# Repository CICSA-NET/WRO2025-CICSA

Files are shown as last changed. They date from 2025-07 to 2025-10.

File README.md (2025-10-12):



This is the official repository of the Team CICSA for the international final of the WRO2025 season in Panamá.

## Follow us!

| Facebook | YouTube | Instagram |
|---|---|---|
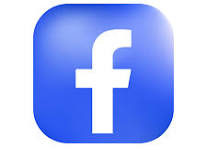
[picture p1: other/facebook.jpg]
Facebook (https://www.facebook.com/share/1A1hz6zQSn/)
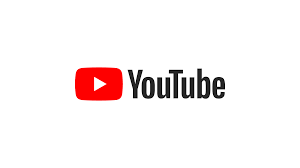
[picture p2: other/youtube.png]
YouTube (https://www.youtube.com/@CICSA_Academia)
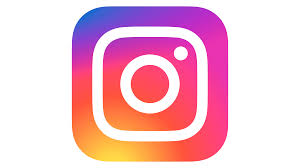
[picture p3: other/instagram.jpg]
Instagram (https://share.google/ZzGMFZOurGsjhWN2D)
|  |  |  |

## Contents.
**Folders**
- [📁 Models](./models/)
- [📁 Other](./other/)
- [📁 Schemes](./schemes/)
- [📁 Src](./src/)
- [📁 T-photos](./t-photos/)
- [📁 V-photos](./v-photos/)
- [📁 Video](./video/video.md)

**Index**

- [The team](#The-team)
- [The Challenge.](#The-Challenge)
- [Robot Overview](#Robot-Overview)
- [Robot construction guide.](#Robot-construction-guide)
- [Engineering materials](#Engineering-materials)
- [Mobility Management](#Mobility-Management)
- [Power and Sensor Management](#Power-and-Sensor-Management)
- [Obstacle management](#Obstacle-management)
- [Performance videos](#Performance-videos)
- [Digital Engineering Logbook](https://github.com/CICSA-NET/WRO2025-CICSA/blob/main/other/README.md)
- [Final Remarks and future work](#Final-remarks-and-future-work)
- [References](#References)

___
## The team.
====

CICSA WRO 2025 - Future Engineers

Coach **Sergio Iván Hernández Ruiz**

Coach Sergio Iván provides the technical guidance and leadership required to keep Team CICSA on track. With extensive experience in robotics, he helps us navigate complex challenges, refine our designs, and develop solutions that work in competitive and real-world settings.

Sergio Iván has been the director of the CICSA robotics academy since 2015 and has participated in events organized by the WRO since 2019.
***
**Members:**

**Iván Ramón Hernández Gónzalez**, at 22 years old, he studies Electronics Engineering at the Instituto Tecnológico de Nogales. He participated in the WRO regional competition in 2019, obtaining 1st place in the preparatory category in the city of Guadalajara, Jalisco, México. In 2024, he was the coach of the CICSA team that participated in the ChampionShip of Italy, with an outstanding performance. In 2025, he participated as a coach in the Robotics Championship, an event affiliated with the Baja Robotics League, in Tijuana, Baja California, México, obtaining 2nd place in the Zumo Kit educational competitions category.
***
**Sergio Amid Hernández Gónzalez**, at 19 years old, he studies Software Engineering at Kuepa University. He has participated in numerous competitions, including: the 2019 WRO Regional in Guadalajara, Jalisco, México, where he obtained 1st place. In 2024, in the city of Mexicali, Baja California, México, they obtained 1st place in the preparatory category. He was part of the Mexican robotics team that represented Mexico at the ChampionShip in Italy in 2024.
***
**Xiara Gabriela Alcantar Dorame**, she is 20 years old, studies Mechatronics Engineering at the Universidad Tecnológica de Nogales, in 2020 she was part of the CICSA team that would represent CICSA in the regional competition, but the pandemic prevented the event from taking place, for 2025 she will be part of the CICSA representative in the National competition in Rosarito, Baja California, México.

___



[📁 T-photos](./t-photos/)

[Menu](#Contents)

___

## The Challenge.
====

The WRO Future Engineers challenge pushes students to create fully autonomous self driving vehicles. Each robot must:

- Navigate a dynamically randomized track.
- Detect and avoid colored obstacles (green/red blocks).
- Execute a parallel parking maneuver.

Scoring is based on:
- Performance on track.
- Obstacle handling.
- Documentation quality.
- Innovation and engineering rigor.

Objective:
Design and build a mobile robot capable of autonomous navigation using: 
* Image recognition for object detection.
* PID control to maintain a safe distance from obstacles using ultrasonic sensors.
* Communication between Raspberry Pi 5 and ESP32 to divide tasks between heavy processing (vision) and real-time control (motors and sensors).

**Open challenge.**



**Obstacle challenge.**



For more indo visit: [WRO Official Site](https://wro-association.org/)

[Menu](#Contents)
___

## Robot Overview.
====

| Front | Back | Top |
|---|---|---|
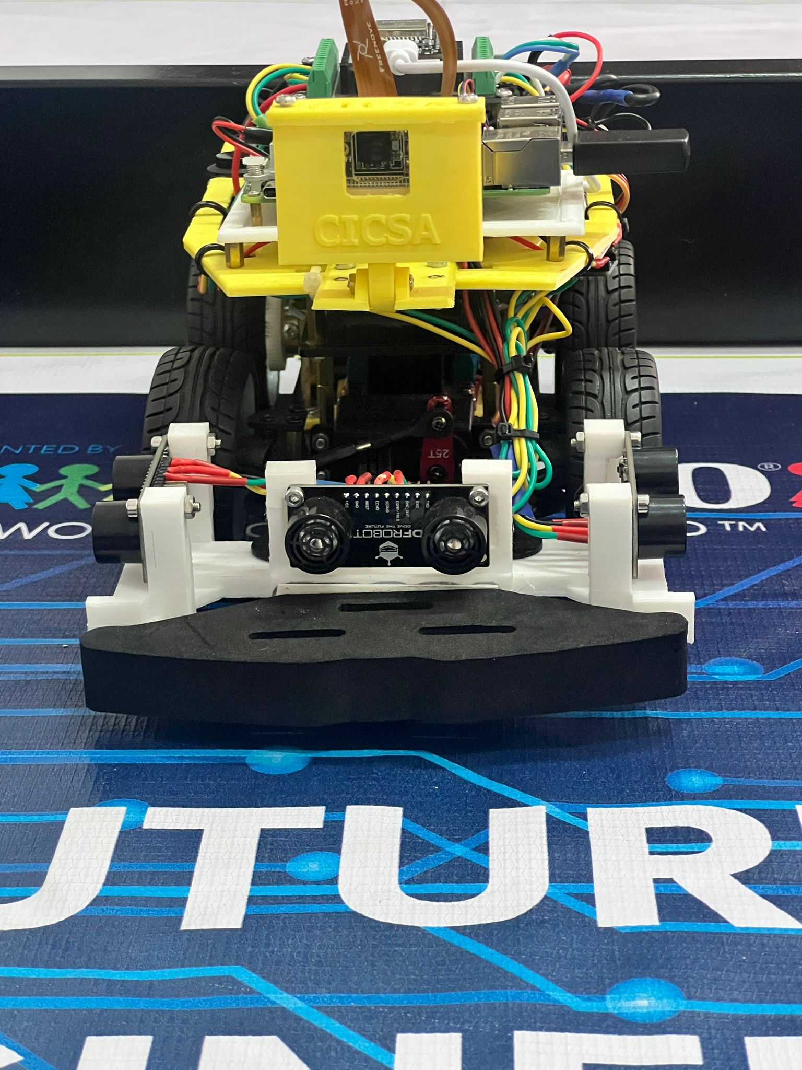
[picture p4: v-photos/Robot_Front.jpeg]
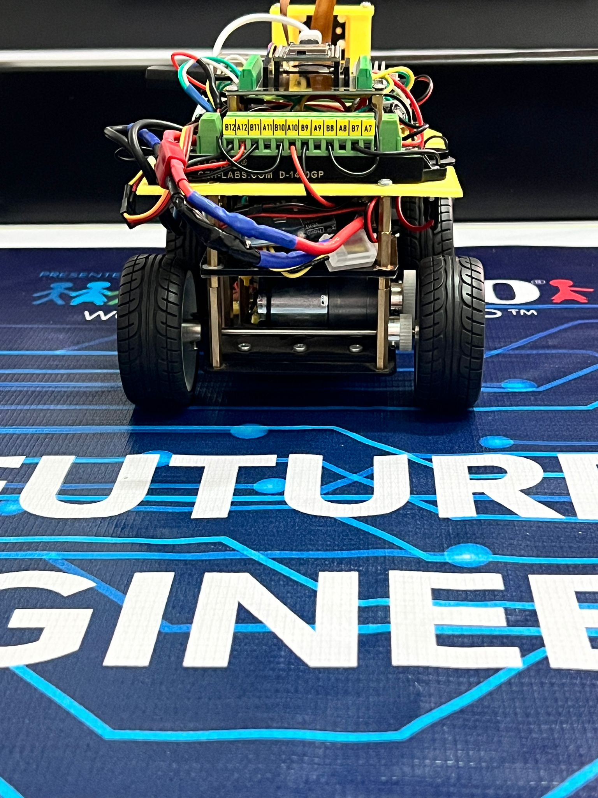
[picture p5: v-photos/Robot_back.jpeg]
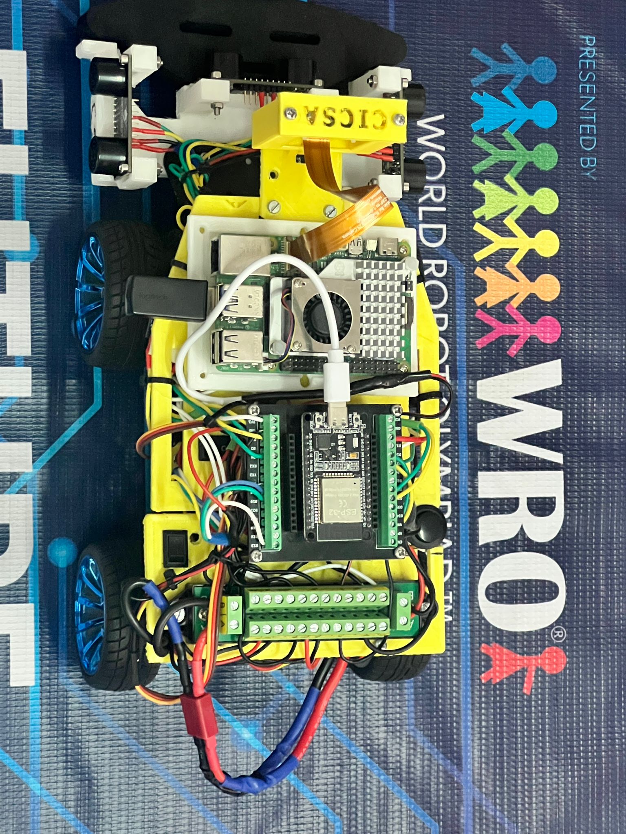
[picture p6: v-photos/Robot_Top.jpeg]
|  |  |  |

| Bottom | Left | Right |
|---|---|---|
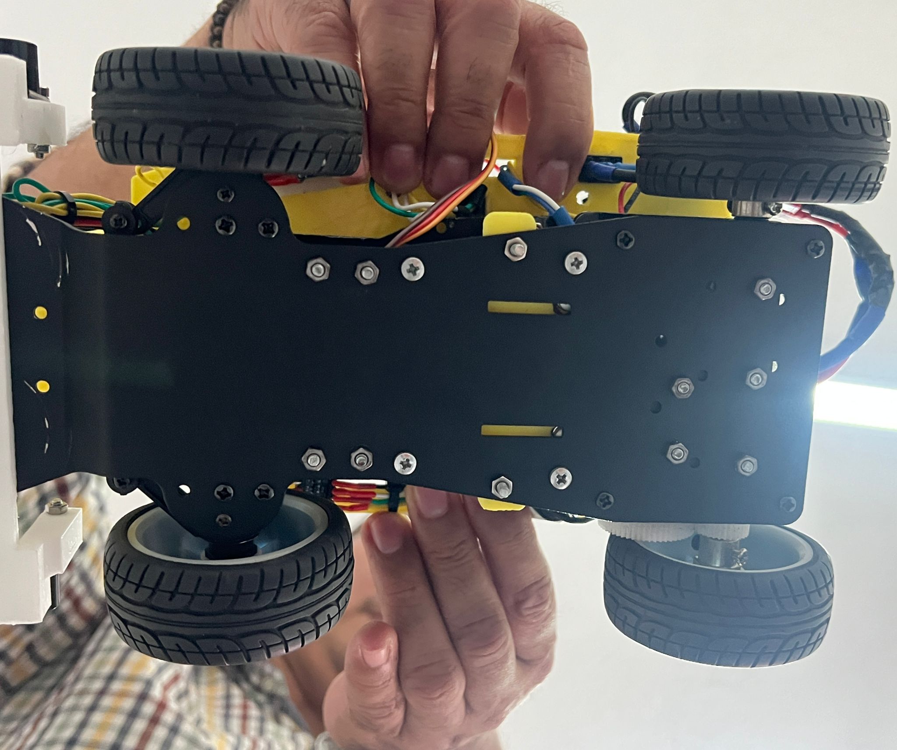
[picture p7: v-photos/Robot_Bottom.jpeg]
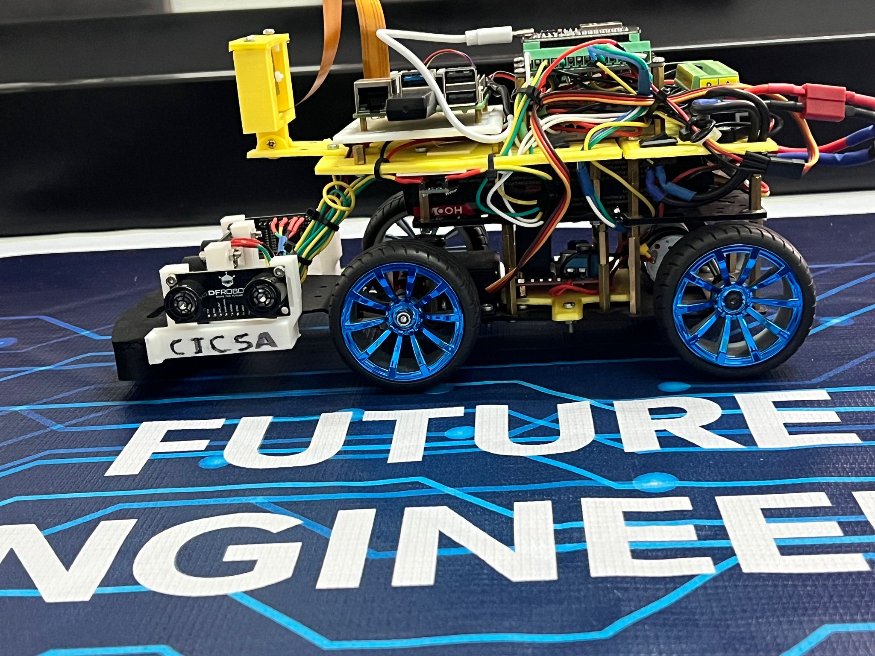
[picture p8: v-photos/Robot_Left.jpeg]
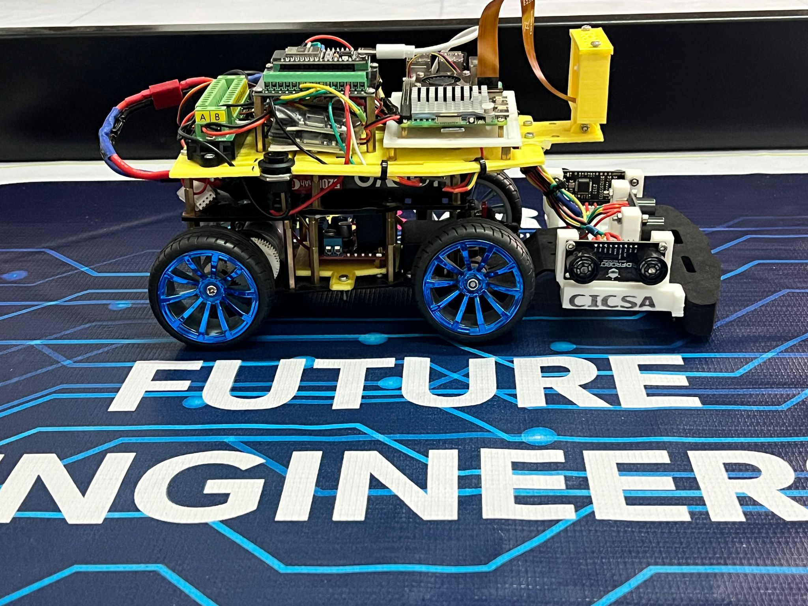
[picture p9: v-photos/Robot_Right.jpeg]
|  |  |  |

| Side Dimensions | Front Dimensions | Robot Weight| 
|---|---|---|
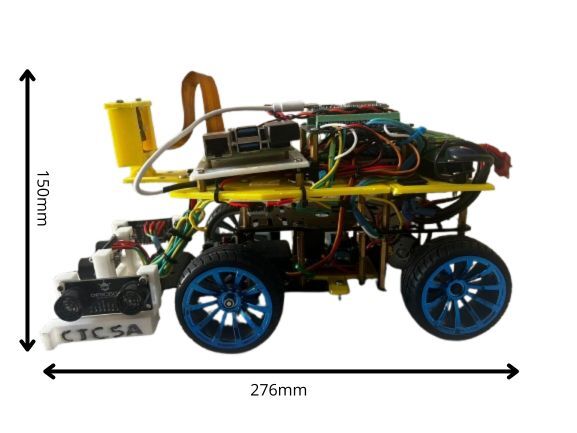
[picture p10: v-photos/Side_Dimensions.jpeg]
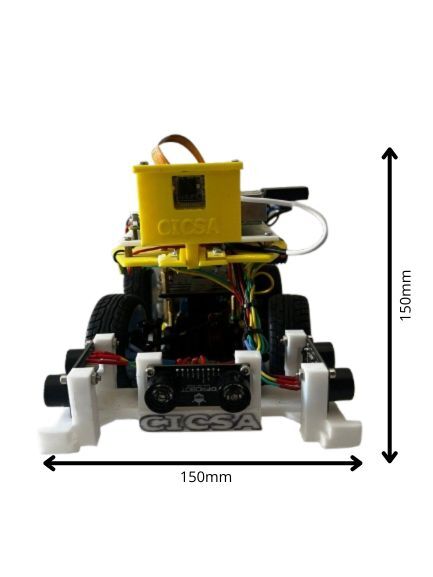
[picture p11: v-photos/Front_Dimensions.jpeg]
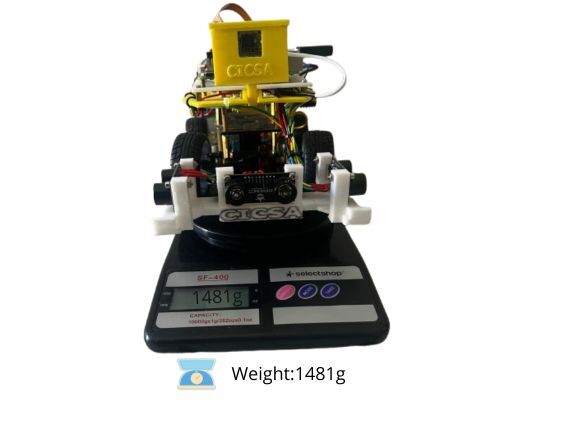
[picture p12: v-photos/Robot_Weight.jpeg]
|  |  |  |

| Evolution of the robot |
|---------------|
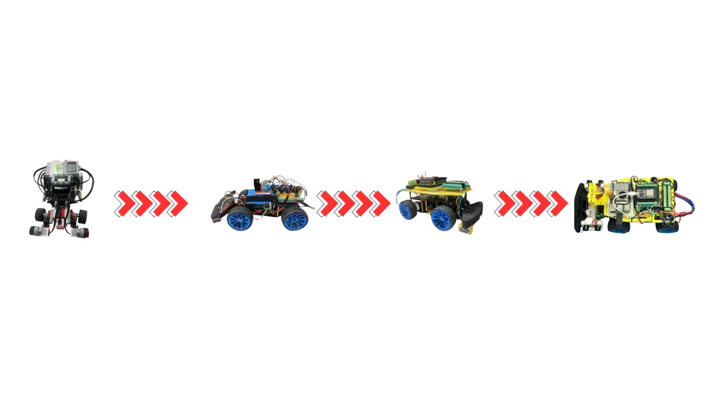
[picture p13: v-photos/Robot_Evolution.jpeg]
|  |

[Menu](#Contents)
___

## Robot construction guide.
====

**Assembly Guide.**

This guide provides step-by-step instructions for assembling the robot chassis. It includes mechanical installation, electrical wiring, and safety notes for robotics projects using ESP-32, Raspberry Pi 5, camera and sensors.

---

**Component List.**

| Component | Quantity | Description |
|---|---|---|
| JGA25-370 DC Motor | 1 | Gear motor for drive system |
| Servo Motor | 1 | For front steering mechanism |
| Wheels | 4 | Includes M4 nuts |
| Bearings (large/small) | 8 | 2 per wheel |
| Steering Cup | 2 | For front wheels |
| Short Ball Head | 1 | Connects servo to steering cup |
| Steering Rod | 2 | Length: 65 mm |
| M3×5mm Screws | 4 | Servo mounting |
| M3×8mm Screws | 4 | Pillar mounting |
| M2.5×10mm Screws | 2 | Steering rod mounting |
| M3×22mm Copper Pillars | 4 | Standard chassis height |
| M3×16mm Copper Pillars | 4 | Extended front option |
| Rocker Switch | 1 | Power control |

---

**Pre-Installation Checks.**

**Servo Motor.**
- Connect and calibrate to **90°** before installation.
- Use test code or compatible software.

**DC Motor.**
- Power directly to verify rotation.
- **Red dot** indicates positive terminal.

---

**Wheel Assembly Steps.**

1. Insert rotating shaft.
2. Add large bearing.
3. Install steering cup.
4. Add small bearing.
5. Insert pin.
6. Attach hex coupler.
7. Mount wheel.
8. Secure with M4 nut.

>  Ensure bearings are parallel and wheel rotates freely.

---

**Servo & Steering Assembly.**

- Mount servo to L-bracket using M3×5mm screws.
- Connect short ball head between servo and steering cup.
- Attach steering rods using M2.5×10mm screws.

---

**Chassis Mounting.**

- Use M3×22mm pillars and M3×8mm screws for standard setup.
- For extended front space (e.g. larger battery), use M3×16mm pillars.
- [Place the base to hold the connector](models/base_conector_v3.STL)
- [Place the base to hold the L298N](models/base_l298n.stl)
- [Place the main base](models/base_principal_V6.STL)
- [Place the base to hold the support of the camera](models/base_camera_v2.STL)
- [Place the base to hold the camera](models/base_camera2_V2.STL)
- [Place the camera base cover](models/tapa_camera.STL)
- [Place the base to hold the sensors UM](models/base_urm37_v7.STL)
- [Place the base to hold the Rasoberry Pi 5](models/Base_Pi_5_v5.STL)
- [Place the shield that contains the esp32](https://www.mercadolibre.com.mx/screw-shield-adaptador-de-terminales-esp32-30-pines/p/MLM2038781113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)

For more information regarding 3D printed parts: [📁 Models](./models/)

---

**Electrical Wiring.**

**Servo Motor.**

| Wire Color | Function |
|---|---|
| Brown | GND |
| Red | VCC |
| Yellow | Signal |

**Power Switch.**

- Connect **in series** with the positive (red) wire.
- Enables safe power control.

---

**Safety Notes.**

- Do not operate in humid environments.
- Avoid reverse polarity.
- Prevent short circuits.
- Double-check connections before powering on.

---

**Board Compatibility.**

Mounting holes support:

- ESP-32 base
- Camera base
- Raspberry Pi 5 base

---

Original PDF: [Elecrow 4WD Car Installation Instructions](https://www.elecrow.com/download/4wd_CAR_Install_instructions.pdf)

---

[Menu](#Contents)
___

## Engineering materials.
====

This repository contains engineering materials of a self-driven vehicle's model participating in the WRO Future Engineers competition in the season 2025.

| Quantity | Component |Link |
|---|---|---|
| 1 | Raspberry Pi 5 (16GB) |[Amazon](https://www.amazon.com/gp/product/B0DSPYPKRG/ref=ox_sc_act_title_6?smid=A02211013Q5HP3OMSZC7W&psc=1) |
| 1 | ESP-WROOM-32 |[Amazon](https://www.amazon.com/ESP-WROOM-32-Development-Microcontroller-Integrated-Compatible/dp/B08D5ZD528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) |
| 1 | Camara Freenove 8MP |[Amazon](https://www.amazon.com/Freenove-8MP-Raspberry-Adjustable-Viewing/dp/B0BZYPBS17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) |
| 1 | Driver de motor L298N |[Amazon](https://www.amazon.com/JTAREA-Stepper-Driver-H-Bridge-Mega2560/dp/B0D2RJV2VX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) |
| 1 | Terminal Block OONO D-1410GP |[Amazon](https://www.amazon.com/Position-Terminal-Distribution-OONO-D-1410GP/dp/B0DXF1GF9Q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) |
| 2 | SoloGood 5V 5A (2s/3s/4s) |[Amazon](https://www.amazon.com/SoloGood-Module-Quadcopter-Airplane-Servo/dp/B0C3GVGYDS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) |
| 1 | External UBEC 5V BEC Multi-Purpose Step-down Power Supply Module Full Shielding Antijamming for FPV Airplane (1PC 5V 7A) |[Amazon](https://www.amazon.com/dp/B0D7MR48LB?ref=ppx_yo2ov_dt_b_fed_asin_title&th=1) |
| 1 | Battery LiPo HOOVO 11.1V 3S 5200mAh 60C |[Amazon](https://www.amazon.com/HOOVO-11-1V-5200mAh-Softcase-Helicopter/dp/B0BWJH8G35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) |
| 1 | Chasis 4WD + servo S3003 |[Elecrow](https://www.elecrow.com/4wd-smart-car-robot-chassis-for-arduino-servo-steering.html) |
| Varios | Jumper y cables |[Amazon](https://www.amazon.com/-/de/dp/B01EV70C78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)|
| 1 | Cable 24 AWG PUDKLE (157ft) |[Amazon](https://www.amazon.com/dp/B0DK57KRCT?ref=ppx_yo2ov_dt_b_fed_asin_title&th=1) |
| 2 | Logic Level Converter Bi-Directional Shifter Module 3.3V to 5V |[Amazon](https://www.amazon.com/dp/B07CXMDJC2?ref=ppx_yo2ov_dt_b_fed_asin_title) |
| 1 | Screw shield adaptador ESP-32 |[Mercado Libre](https://articulo.mercadolibre.com.mx/MLM-2162499429-screw-shield-adaptador-de-terminales-esp32-30-pines-_JM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) |
| 1 | 6pcs DIN Rail Terminal Blocks |[Amazon](https://www.amazon.com/dp/B0BQ6GWW3T?ref=ppx_yo2ov_dt_b_fed_asin_title&th=1) 
| 3 | Ultrasonic sensors URM37V5.0 |[DigiKey](https://www.digikey.com/en/products/detail/dfrobot/SEN0001/6588449) |
| 1 | USB to TTL Converter |[Amazon](https://www.amazon.com/DSD-TECH-SH-U09C5-Converter-Support/dp/B07WX2DSVB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) |

Estimated total cost ==> **$ 327.00 US dollars**.

| Component | Function / Description |
|---|---|
| Raspberry Pi 5 | Image processing and navigation logic |
| ESP32 | Real-time servo control with PID algorithms and read sensors |
| Camera | Captures images for computer vision |
| ARM37V5 (x3) | Distance measurement for obstacle avoidance |
| L298N Motor Driver | Controls DC motors |
| DC Motor | Robot movement |
| Lipo Battery | Portable power source |
| Voltage Regulator | Stabilizes voltage for sensitive components |
| UART Communication | Link between Raspberry Pi and ESP32 |
| 2WD / 4WD Chassis | Physical structure of the robot |
| Servo motor | Controls steering direction | 

Software & Libraries Overview
| Platform | Language / Frameworks | Key Functions / Roles |
|---|---|---|
| Raspberry Pi 5 | Python 3 | Main control logic, image processing |
| | OpenCV | Computer vision (line following, object tracking)|
| | pyserial | UART communication with ESP32 |
| | numpy, imutils | Math operations, image transformations |
| ESP32 | MicroPython | Lightweight firmware for real-time control |
| | machine, time, ustruct | Sensor reading, PWM generation, UART handling |
| | PID function | Servo control |

Workflow Table
| Module | Function / Task |
|---|---|
| Raspberry Pi 5 | Captures image via camera |
| | Processes image using OpenCV (color) |
| | Determines direction. |
| | Sends commands to ESP32 via UART |
| ESP32 | Receives commands from Raspberry Pi |
| | Reads ultrasonic sensor data |
| | Applies PID control to maintain safe distance |
| | Controls motors and servo using PWM |

[Menu](#Contents)
___

## Mobility Management.
====

**Design Objectives**

The mobility system was designed to meet the following goals:

- **Precision**: Achieve controlled movement and accurate steering.
- **Stability**: Maintain balance and traction across varied surfaces.
- **Mechanical Efficiency**: Use gear ratios to optimize torque and speed.
- **Adaptability**: Respond effectively to terrain changes and obstacles.

**Gear Transmission**: Power is delivered from the motors to the wheels through a custom gear system. Gear ratios were selected to enhance torque for low-speed control and obstacle negotiation.

Mobility is a key factor in robotic performance, especially in competitive environments where precision, stability, and adaptability are essential. This document outlines the mechanical and software strategies used to manage the robot's mobility, featuring a gear-based transmission system and directional control via a servomotor.





The gear transmission is a mechanical system that allows for the modification of angular velocity and torque between two connected shafts. This is achieved by coupling two gears: a driving gear (coupled to the motor) and a driven gear (coupled to the load or wheel).

Based on the previous terms, we use them in the robot as follows:

1. For the free challenge, it is required that the robot has more speed than torque, which is why the driven gear has 54 teeth in relation to the driving gear of 32. If we apply the principle of conservation of mechanical power,
  
   where:  RT =   driven gear teeth / driving gear teeth = 54 / 32 = **1.68**

2. For the obstacle challenge, it is required that the robot moves slowly and with more torque, resulting in the driven gear for this particular challenge having 32 teeth and the driving gear having 54, so that by applying the principle of conservation of power, a decrease in speed is obtained, but torque increases in the following proportion:

   where:  RT =   driven gear teeth / driving gear teeth = 32 / 54 = **0.59**

The motor is controlled using the pulse width modulation technique. Pulse Width Modulation (PWM) is a widely used technique for controlling the speed of DC motors by adjusting the effective voltage applied to the motor terminals. Instead of varying the actual supply voltage, PWM rapidly switches the motor’s power on and off at a fixed frequency, modulating the duration of the “on” time within each cycle—this is known as the duty cycle. The motor’s speed is directly influenced by the duty cycle of the PWM signal. A higher duty cycle means the motor receives power for a greater portion of each cycle, resulting in a higher average voltage and increased rotational speed. Conversely, a lower duty cycle reduces the average voltage and slows the motor down. The configuration parameters are shown below:

**These are the parameters defined for the open-category challenge:**

enable = PWM(Pin(21), freq=1000)        # Motor PWM enable

enable.duty_u16(35000)                  # Set duty cycle to ~53.4%

- Pin(21): Refers to GPIO pin 21 on the microcontroller (ESP32). This pin is physically connected to the motor driver’s (L298N) enable input, which expects a PWM signal.
- PWM(...): Initializes a PWM object on that pin.
- freq=1000: Sets the PWM frequency to 1000 Hz (1 kHz), meaning the signal completes 1000 cycles per second.
- duty_u16(...): Sets the duty cycle using a 16-bit value (range: 0 to 65535).
- 35000: Represents the “on” time of the PWM signal. The duty cycle percentage is:
  Duty Cycle(%) = (35000 / 65535) * 100                **approx 53.4\%**
- This means the signal is high (ON) for 53.4%.
- Average Voltage: The motor receives approximately 53.4% of the supply voltage. If V = 11.1 V, then:
  V = 11.1V * 0.534      **approx 6V**

Based on the measured values and the technical specifications provided by the manufacturer, the following results are obtained:

| Parameter | Measured Value | Unit |
|---|---|---|
| No-load Speed | 646 | RPM |
| No-load Current | 0.1 | A |
| Rated Torque | 0.23 | Kg-cm |
| Power | 1.5 | W |
| Load Speed | 516 | RPM |
| Load Current | 0.8 |  A |
| Stall Torque | 2 | Kg-cm |
| Stall Current | 2 | A |
| Operating Voltage | 6.0 | V |

[Reference](https://www.elecrow.com/4wd-smart-car-robot-chassis-for-arduino-servo-steering.html)

**The following parameters were defined for the obstacle challenge:**

- 26000: Represents the “on” time of the PWM signal. The duty cycle percentage is:
  Duty Cycle(%) = (26000 / 65535) * 100                **approx 39.6\%**
- This means the signal is high (ON) for 39.6%.
- Average Voltage: The motor receives approximately 39.6% of the supply voltage. If V = 11.1 V, then:
  V = 11.1V * 0.396      **approx 4.39V**

Based on the measured values and the technical specifications provided by the manufacturer, the following results are obtained:

| Parameter | Measured Value | Unit |
|---|---|---|
| No-load Speed | 472 | RPM |
| No-load Current | 0.073 | A |
| Rated Torque | 0.263 | Kg-cm |
| Power | 1.0 | W |
| Load Speed | 377 | RPM |
| Load Current | 0.58 |  A |
| Stall Torque | 2 | Kg-cm |
| Stall Current | 1.46 | A |
| Operating Voltage | 4.39 | V |

[Reference](https://www.elecrow.com/4wd-smart-car-robot-chassis-for-arduino-servo-steering.html)

**Directional Control**: A high-precision servomotor is used to steer the front axle, allowing for smooth and responsive turns. This setup mimics real-world vehicle steering and improves maneuverability in tight spaces.







The foundation of our chassis design is based on a steering configuration known as the parallel steering model, in which both front wheels turn at the same angle when steering input is applied. This approach, while mechanically straightforward, provides a reliable baseline for mobile robot steering systems—especially when simplicity, symmetry, and ease of implementation are key priorities.



In short, parallel steering was chosen because it strikes a balance between functionality and feasibility. It enables reliable performance while keeping the mechanical and computational demands accessible—perfect for STEM education, prototyping, and early-stage competition builds.

The selection was based mainly on the following reasons:

1. Mechanical Simplicity
- The parallel steering model allows both front wheels to turn at the same angle using a single servo or mirrored linkage system.
- This reduces the number of moving parts and avoids the need for complex geometry or differential steering mechanisms.
2. Ease of Control
- From a programming standpoint, controlling a single angle for both wheels is straightforward.
- It simplifies PID tuning, sensor feedback loops, and integration with basic autonomous navigation systems.
3. Modular Compatibility
- Many commercial chassis kits (like those using MG996R servos or JGA25-370 motors) are designed with parallel steering in mind.
- This makes it easier to integrate with off-the-shelf components and adapt to different platforms.
4. Symmetry and Predictability
- Parallel steering provides predictable turning behavior, which is useful for line-following, maze-solving, or path planning in competition environments.
- It also simplifies documentation, calibration, and debugging.

**Dimensions, Steering Geometry, and Their Impact on Navigation**
The robot designed for the Future Engineers category of the WRO has dimensions of 150 mm in width, 150 mm in height, and 276 mm in length, with a total weight of 1480 grams. These specifications fall within the official limits defined by the competition rules.

**Parallel Steering Geometry with 35° Angles**. 
The robot uses a parallel steering geometry, meaning both front wheels turn at the same angle. In this case, the steering angle is 35 degrees, which provides a reasonable turning capability for wide trajectories. This system is mechanically simple and symmetrical, making it ideal for implementation with servos and direct control.

**Turning Ability and Adjustments in the Open Challenge.**
The 276 mm length results in a larger turning radius, especially in confined spaces. While the 35° steering angle allows functional turns, perfect for use with PID control algorithms.

**Obstacle Avoidance in the Obstacle Challenge.**
The 150×276 mm footprint defines the robot’s contact area with the ground, presenting the following advantages:
-  	Stable base for sensor mounting: The extended length allows for strategic placement of ultrasonic sensors at the front and side, improving obstacle detection and path planning.
-  	Improved traction and weight balance: The 1480 g mass provides sufficient downward force for consistent wheel contact, reducing slippage on ramps or uneven surfaces.
-  	Predictable movement dynamics: The rectangular footprint and parallel steering geometry result in symmetrical turning behavior, which simplifies obstacle avoidance algorithms and makes path corrections more consistent.
-  	Room for modular attachments: The chassis accommodates additional modules such as grippers, cameras, or sensor arrays without compromising structural integrity.
-  	Low center of gravity potential: With proper component placement, the 150 mm height allows for a compact vertical profile, minimizing the risk of tipping during lateral movements or sudden stops.

**Motor and Servo Specifications**

| Parameter | JGA25-370 Gear Motor (12V) | MG996 Servo Motor (6V) |
|---|---|---|
| **Operating Voltage** | 6V / 12V / 24V DC | 4.8V – 6V DC |
| **No-Load Speed** | 12 – 1350 rpm (depends on gear ratio) | 0.14 s/60° (≈ 428°/s) |
| **Rated Speed** | 9 – 1000 rpm | Controlled via PWM (0°–180°) |
| **Stall Torque** | Up to 9 kg·cm (gear ratio dependent) | 11 kg·cm |
| **Rated Torque** | 0.6 – 9 kg·cm | ~2.5 – 9.4 kg·cm (typical range) |
| **Power Output** | 1.6W – 3W | ~2.5W (estimated) |
| **Current Draw** | ≤0.25A rated / ≤3A stall | ~500mA running / 2.5A stall |
| **Rotation Range** | Continuous | 0° to 180° |
| **Control Method** | PWM + gear ratio | PWM signal (50Hz, 1–2ms pulse) |

**JGA25-370 Motor Specifications by Voltage**

| Voltage (V) | No-load Speed (rpm) | Rated Torque (kg·cm) | Power (W) | Load Speed (rpm) | Load Current (A) | Stall Torque (kg·cm) |
|---|---|---|---|---|---|---|
| 3V | 323 | 0.18 | 0.75 | 258 | 0.4 | 1.4 |
| 6V | 646 | 0.23 | 1.5 | 516 | 0.8 | 2.0 |
| 12V | 592 | 0.23 | 2.3 | 475 | 0.6 | 2.0 |
| 24V | 409 | 0.15 | 1.0 | 347 | 0.5 | 1.3 |

>  **Technical Notes**:
> - Best performance observed at **12V**, offering solid torque and peak power.
> - Stall torque values are useful for defining load limits and implementing software protection.
> - Ideal for traction, drive systems, or actuator applications with PWM control.

**Chassis Adaptation and Structural Enhancements**: 

A commercial chassis kit was initially acquired as the mechanical foundation for the robot. However, significant structural and functional improvements were implemented to optimize device integration and system stability.
Custom mounting platforms were designed and fabricated to securely accommodate key components such as the ESP32 microcontroller, the Raspberry Pi 5 single-board computer, the camera module, and the sensor array. These modifications involved redesigning the original base plates to ensure precise alignment, vibration damping, and thermal clearance for high-performance operation.
The updated design also includes reinforced brackets and modular supports that facilitate rapid maintenance and component replacement during competition. These enhancements substantially diverge from the original kit layout, resulting in a more robust, competition-ready architecture.
The following technical drawings illustrate the custom adaptations made to the chassis, highlighting the engineering rationale behind each modification and its impact on system performance. The most critical structural adaptations are presented below. These modifications were implemented to enhance component stability, optimize spatial distribution, and improve overall system integration.
Full CAD models and detailed design files can be found in the  folder, including all custom mounts, sensor brackets, and revised base plates. These designs reflect substantial changes to the original kit configuration, tailored to meet the specific demands of the obstacle and open-category challenges.

**Sensors base.**   
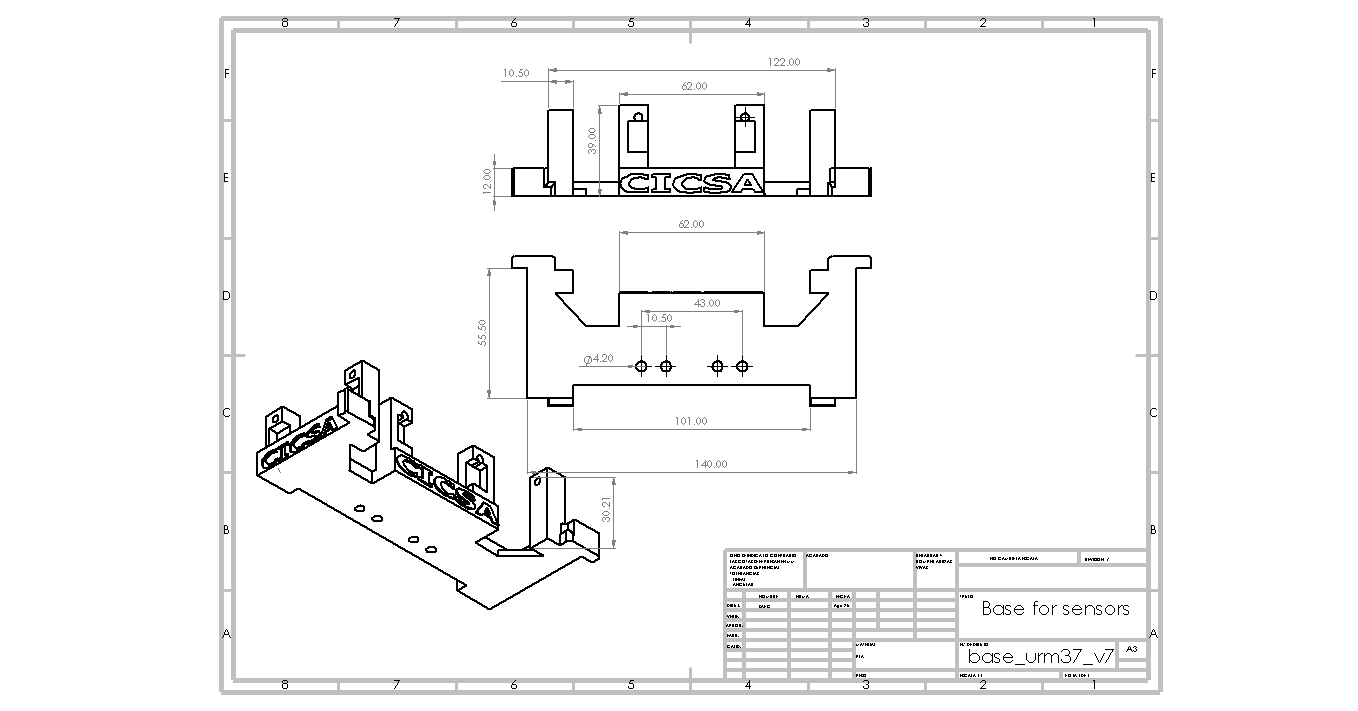
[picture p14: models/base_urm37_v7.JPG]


**Camera base.**
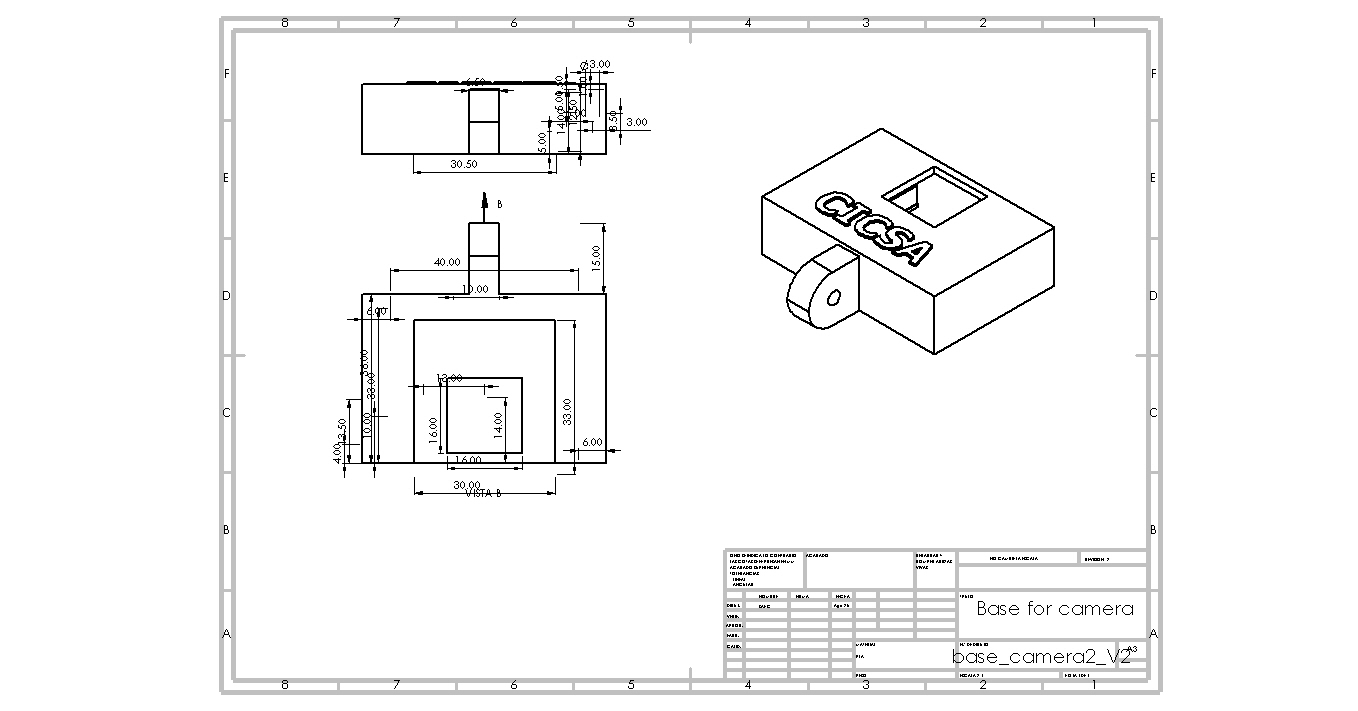
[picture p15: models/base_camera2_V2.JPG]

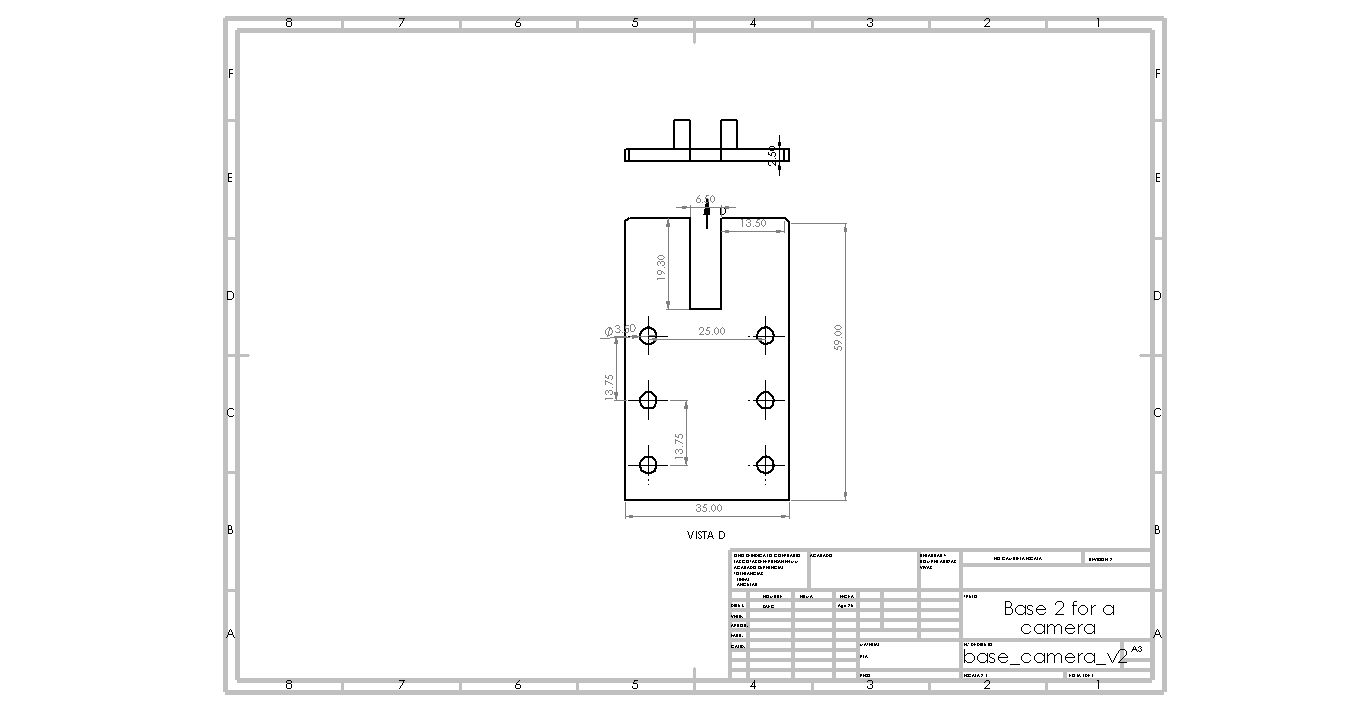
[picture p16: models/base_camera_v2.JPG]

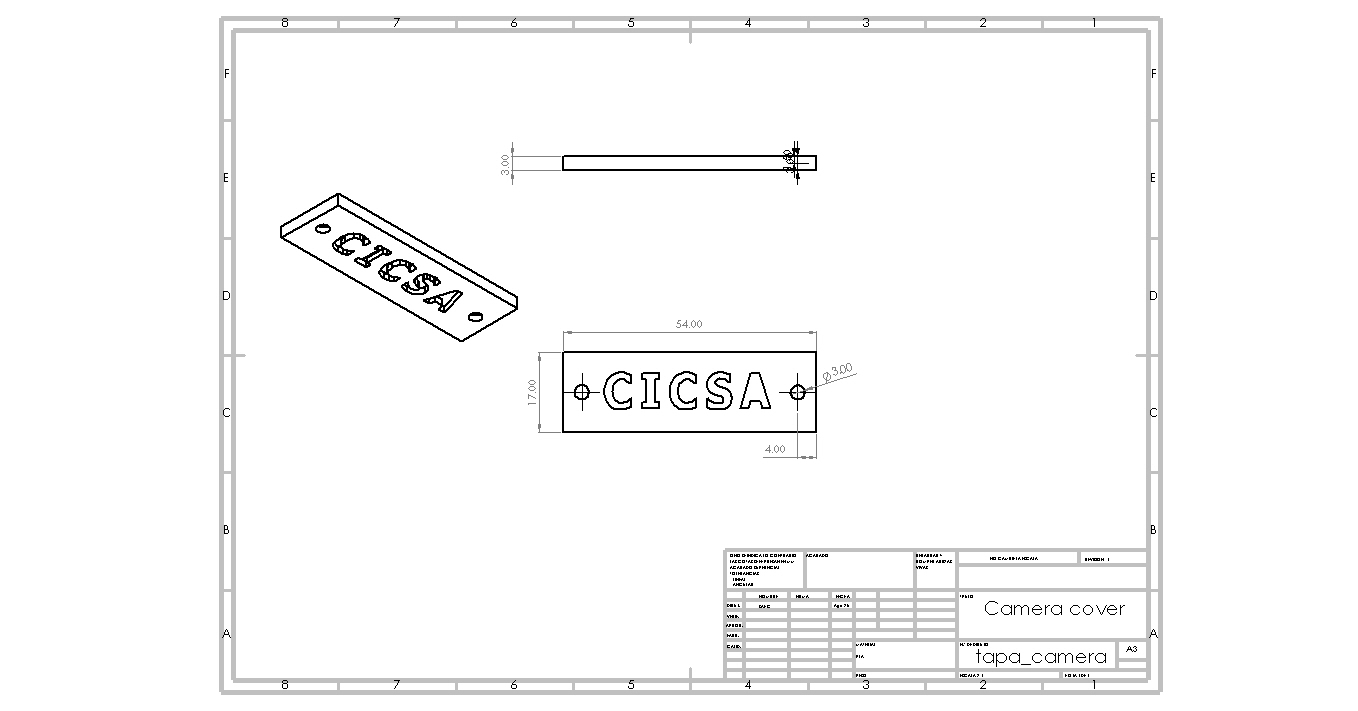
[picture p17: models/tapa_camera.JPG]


**Main base.**
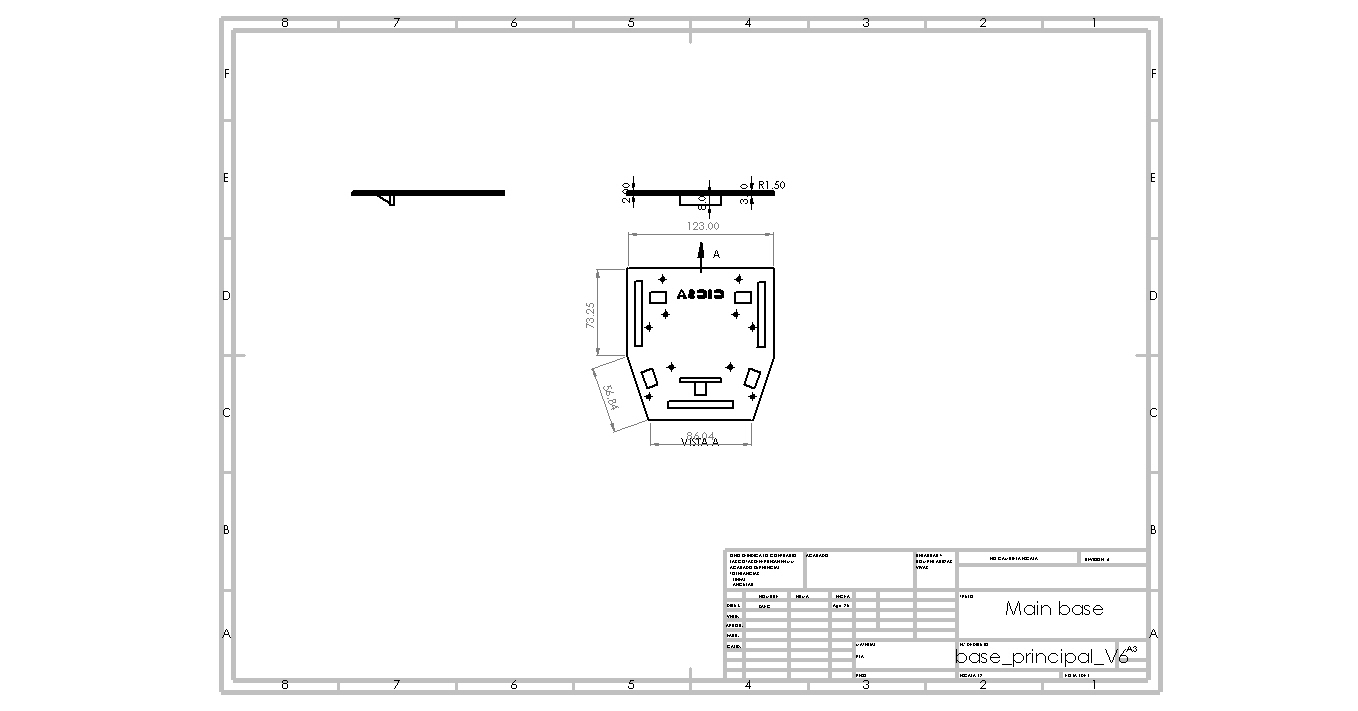
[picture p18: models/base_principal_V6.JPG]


These adaptations ensure modularity, scalability, and ease of maintenance during competition and development phases.

A commercial chassis was selected to optimize structural integrity, motor compatibility, and sensor placement for the mobile robot platform. Below are its key specifications:

| Feature | Specification |
|---|---|
| **Material** | Metal chassis / ABS plastic |
| **Dimensions (L×W×H)** | 248 mm × 146 mm × 70 mm |
| **Wheel Type** | 2WD with rubber tires (65 mm diameter) |
| **Motor Mounts** | Compatible with JGA25-370 gear motors  |
| **Servo Mounts** | Integrated brackets for MG996 servo |
| **Sensor Slots** | Front and side slots for ultrasonic sensors |
| **Battery Compartment**  | Supports 2S/3S Battery LiPo HOOVO 11.1V 3S 5200m |
| **Weight Capacity** | ~1.5 kg payload |
| **Shock Absorption** | Rubber dampers included |

**Software Integration**

- **Motor Control**: PWM signals regulate motor speed, while gear ratios provide mechanical tuning. The servomotor is controlled via angle commands for directional adjustments.
- **Error Handling**: The system includes routines to detect gear misalignment, servo overload, or terrain anomalies, triggering corrective actions when needed.

GeneralProgramOpen

get_data

get_distance

turn_servo

turn_robot

pid

Start_diagram

The complete code and description of this can be found at:  [📁 Src](./src/)

**Interaction of the PID control algorithm with the robot.**

A discrete PID control algorithm was designed and implemented, whose output is responsible for controlling the direction of the robot, through the steering system described above. Establishing a reference of 250 mm to a wall laterally, that is, the main task of the controller is to keep the robot at a distance of 250 mm from the wall. The figure shows the closed-loop control system in the Z domain. R(Z) is the system reference, in this case it has a value of 250 mm, E(Z) represents the system error, which is calculated with the measurement of the ultrasonic sensor minus the input reference, D(Z) is the PID control algorithm, U(Z) is the control action output of the controller, G(Z) is the plant, Y(Z) represents the system output. 

R_z_



The process to be controlled is called plant G(Z), which can represent any physical process whose response must be through an appropriate control action, by satisfactory response it is defined that the output Y(Z), is forced to follow the input reference R(Z), despite the presence of disturbances. The process of keeping Y(Z) close to R(Z), is called the regulation process. The microcontroller uses clock signals in order to synchronize the flow of information, all the time that the microcontroller invests in reading the response of the plant, processing the information and writing the control action, is known as sampling time T. The control action consists fundamentally in calculating the control signal U(Z), see next equation [1]:



Developing equation 01, the result is equation 02, which is finally the control action of the PID algorithm to be implemented.



The reference distance established for the system is 250 mm, which is the distance the robot must maintain in relation to the wall. Table below shows the parameters with which we performed the tests, in order to obtain a point at which the PID controller operates as optimally as possible. The parameters were tuned to the point that most quickly obtained the desired reference and was most stable. It should be noted that this procedure was performed using the tuning method.

Resulting in the most optimal values for the robot:
**Kp = 1.4, Ki = 0.01,  Kd = 0.25 and T=0.15 seg.**

**Performance Evaluation**

Mobility was tested under various conditions:

- **Obstacle Navigation**: The robot demonstrated reliable steering and movement over uneven surfaces and around barriers.
- **Turning Radius**: The servomotor-based steering allowed for tighter turns compared to differential drive systems.
- **Load Testing**: Gear ratios and servo torque were validated under different payloads to ensure consistent performance.
- **Energy Efficiency**: Power consumption was monitored to balance torque output, steering precision, and battery endurance

---

>  **Design Rationale**:
> - Chosen for its modularity and ease of integration with ESP32 and Raspberry 5.
> - Provides stable base for F1-style mobility and sensor calibration.
> - Lightweight yet durable, ideal for competition and field testing.
>

**Engineering Principles Applied**

The design and implementation are grounded in core engineering concepts:

- **Angular velocity**: Used to calculate linear displacement from motor rpm.
- **Torque**: Determines traction force and load capacity.
- **Power**: Guides battery selection and motor efficiency.
- **Mass distribution**: Ensures stability and maneuverability.

**3D Printed Components**

Complementary 3D-printed parts used to enhance the commercial chassis are included in the `models/` folder located at the top level of this repository.

These components include:
- **Sensor mounts** (ultrasonic)
- **Battery holders**
- **Structural reinforcements** and expansion adapters

>  All files are provided in `.STL` format and are ready for slicing and printing. Designed for compatibility with standard FDM printers and PLA materials.

[Menu](#Contents)
___

## Power and Sensor Management.
====

Efficient energy and sensor management are essential for reliable vehicle performance. This section outlines the power strategy, sensor selection, and system integration used in the robot.
Three sensors were used to provide the microcontroller (ESP32) with the necessary information to navigate the track and overcome various challenges. One sensor is mounted on the right side of the vehicle to work in conjunction with the PID controller, maintaining a specific distance from the wall. Another sensor is placed on the left side, performing the same function on the opposite side. A third sensor is positioned facing forward to monitor when the robot approaches the front wall.

**Pinout of the main components.**
| ESP-32 | Raspberry PI 5 | URM37 |
|---|---|---|
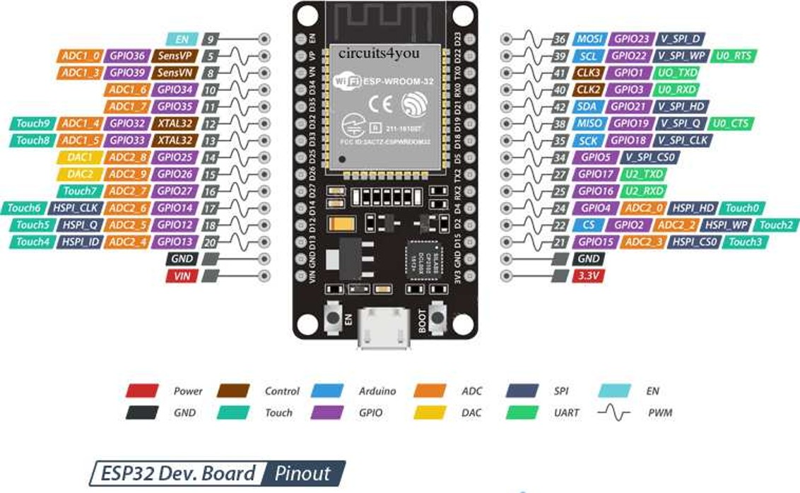
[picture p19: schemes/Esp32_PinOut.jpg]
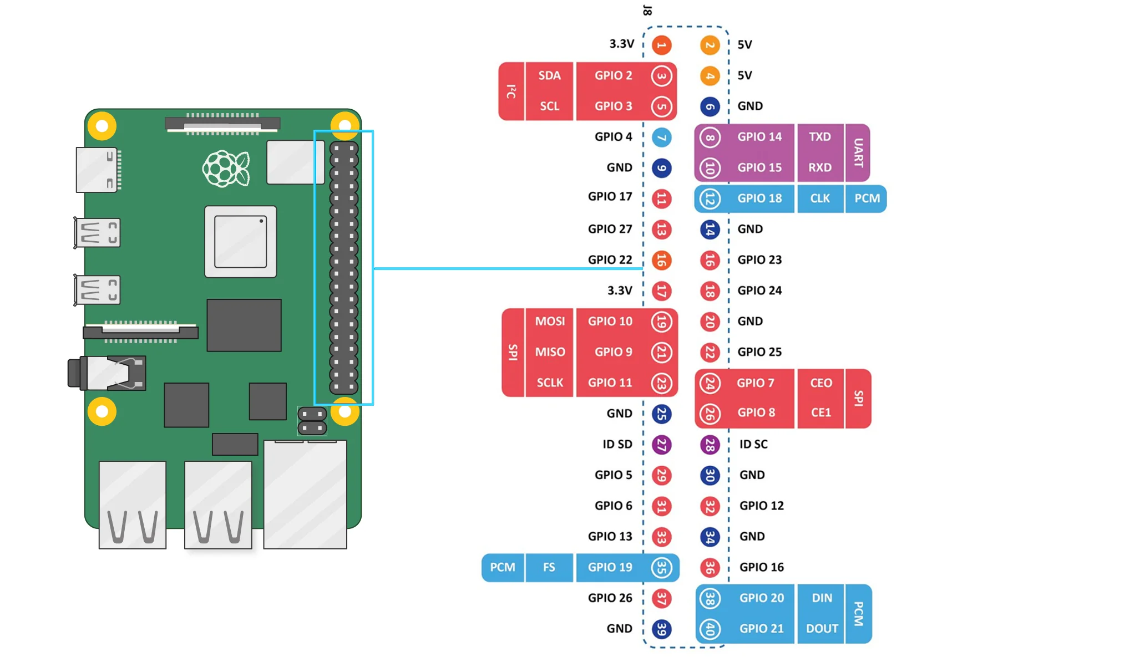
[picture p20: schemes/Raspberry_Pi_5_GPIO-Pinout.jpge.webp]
|  |  |  |

**Main connection diagram.**
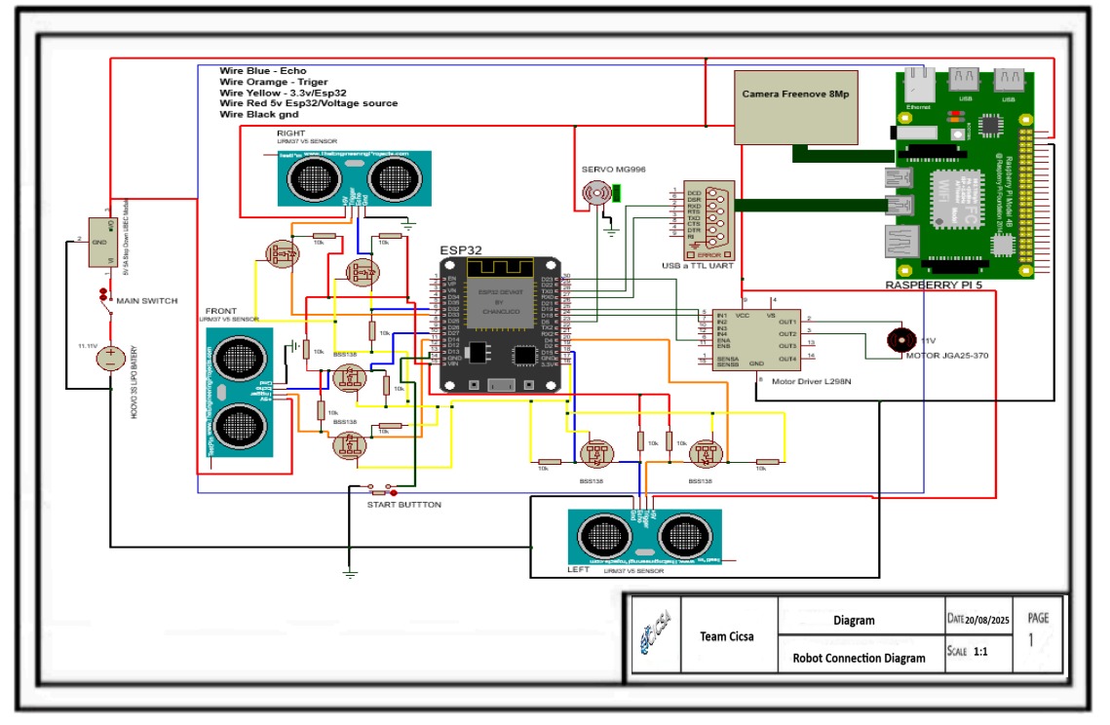
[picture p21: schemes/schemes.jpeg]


**Current Consumption Analysis – Robotic System**

| Component | Quantity | Voltage (V) | Current per unit (A) | Total current (A) | Max total current (A) |
|---|---|---|---|---|---|
| JGA25-370 Motor | 1 | 11 | 0.6 | 0.6 | 0.6 |
| MG996R Servo | 1 | 5.0 | 0.5 | 0.5 | 1.0 |
| Raspberry Pi 5 | 1 | 5 | 1.2 | 1.2 | 3.5 |
| ESP32 | 1 | 5 | 0.08 | 0.08 | 0.08 |
| URM37V5 Sensor | 3 | 5 | 0.02 | 0.06 | 0.06 |
| L298N (logic circuit)  | 1 | 5 | 0.05 | 0.05 | 0.05 |
| **Estimated Total** | — | — | — |👉 **2.49 A** | 5.29 A |

**Power Supply Strategy**

The power system is designed to support motors, servos, microcontrollers, and sensors simultaneously. Key considerations includes two challenges, each powered by a different voltage source.
For the open challenge and the obstacle challenge, the system is powered by a battery that supplies 5200 mA.
Detailed battery specifications are provided below

- **Battery type**  
  - Battery LiPo HOOVO 11.1V 3S 5200mAh 60C

- **Power regulation**  
  - Buck converters or dedicated power rails to prevent voltage drops and protect sensitive components

**Sensor Selection and Justification**
Three ultrasonic sensors [URM37 V5.0](https://wiki.dfrobot.com/URM37_V5.0_Ultrasonic_Sensor_SKU_SEN0001_) were selected to provide the robot with positioning information on the track.
They were mounted on the front of the robot: one on the right side, one on the left side, and one in the center.
This configuration allows the robot to detect lateral boundaries and maintain alignment during navigation.



The side mounted sensors provide the system with distance measurements between the robot and the lateral walls.
A PID control algorithm was implemented to maintain a consistent, predefined distance from these walls during navigation.
The center sensor supplies data regarding the robot’s proximity to the front wall, enabling forward obstacle detection and alignment.
Each sensor contributes to navigation, obstacle detection, or environmental awareness:

| Sensor | Purpose | Protocol | Power Notes |
|---|---|---|---|
| 3 URM37V5.0 | Distance measurement | Digital  | Low consumption |

**Specification:**
- Operating voltage: 3.3V ~ 5.5V.
- Operating current: 20 mA.
- Working temperature: -10°C ~ 70°C.
- Detecting range: 2cm - 800cm (ultimate range 1000cm).
- Resolution: 1cm.
- Accuracy:1%.
- Measuring period: <100ms (Max).
- Dimmensions: 22mm X 51mm.
- Weight: about 25g.

Robot_Sensor

Technical Discussion: **Justification for the Frontal Triangular Sensor Layout.**
This frontal sensor configuration was selected to optimize obstacle detection, corner recognition, and real-time control feedback. The measurements obtained from the side-mounted sensors serve as inputs for calculating the error relative to a reference in the PID control algorithm. The layout provides a wide horizontal sensing field while maintaining directional specificity:
- Left Sensor: Detects lateral obstacles and corner proximity on the robot’s left flank. It is essential for initiating left turns and feeds distance data into the PID control algorithm.
- Center Sensor: Functions as the primary forward-facing detector. It monitors frontal clearance, triggers corner detection based on threshold distance, and supports collision avoidance logic. It also serves as a reference for the PID controller, indicating when the robot approaches a frontal wall and needs to initiate a turn.
- Right Sensor: Mirrors the role of the left sensor, enabling symmetric detection on the robot’s right flank. It supports right turns and contributes to PID error calculation for wall-following and lane-change decisions.
This triangular arrangement allows the robot to:
- Disambiguate corners from flat walls by comparing differential readings across the three sensors.
- Reduce decision latency by placing all sensors on the frontal plane, ensuring immediate access to environmental data aligned with the robot’s forward motion vector.
- Enhance control precision by providing real-time feedback to the PID algorithm, enabling smoother navigation and more reliable maneuver execution.
By aligning sensor placement with the robot’s direction of travel and control logic, this design ensures that all critical navigation decisions are based on immediate frontal context—improving responsiveness, stability, and overall system robustness.

**Vision System Integration** Freenove 8MP Camera Module.
We integrated the Freenove 8MP Camera Module to enable real time visual sensing, environmental awareness, and documentation capabilities. This section outlines the technical rationale, integration strategy, and performance considerations of the camera within our system architecture.



1. Engineering Justification.
- Sensor Type: 8MP CMOS sensor with support for 1080p and 720p output, suitable for both high-resolution capture and low-latency streaming.
- Field of View: 120° wide-angle lens enables broad environmental coverage, critical for tasks involving navigation, object detection, or visual inspection.
- Interface: CSI ribbon cable connection ensures high-speed data transfer with minimal latency, directly compatible with Raspberry Pi 5.

2. System Level Integration.
- Power Budgeting: Camera draws power via CSI interface; no additional GPIO or external regulators required, simplifying the power distribution model.
- Mechanical Design: Mounted on a custom 3D printed bracket aligned with the robot’s frontal axis, ensuring consistent field of view during motion.

3. Software Configuration.
- Capture Modes: Configured for both still () and video () modes, with resolution switching based on task demands.
- Processing Pipeline: Integrated with OpenCV for real time image processing, including color segmentation, contour detection, and basic object classification.
- Frame Rate Optimization: Tuned to 30 FPS for responsive feedback while maintaining CPU headroom for concurrent tasks.

4. Applications in Future Engineers Context.
- Visual Feedback for Actuation: Enables closed loop control based on visual cues (e.g., line following, color based sorting).
- Environmental Monitoring: Supports detection of objects, terrain features, or visual markers relevant to the engineering challenge.
- Project Documentation: Used to capture high-quality images and video for technical reports, GitHub logs, and sponsor presentations.

5. Limitations and Engineering Tradeoffs.
- Lighting Sensitivity: No onboard IR filter or illumination; external LED modules recommended for low light environments.
- Fixed Focus Lens: Depth estimation requires stereo vision or auxiliary sensors (e.g., ultrasonic or ToF).
- Bandwidth Constraints: High-resolution streaming may impact CPU load; offloading via hardware acceleration or resolution scaling is advised

The camera was mounted at the front of the robot, with an inclination angle of approximately 20 degrees. This positioning allows the camera to capture a forward facing field of view that includes both near ground elements and mid range obstacles. While the tilt angle contributes to the perspective of the captured image, it is not a critical factor for the implemented algorithm. The vision system is designed to process frames using region of interest cropping and perspective normalization, which minimizes the impact of camera orientation. As a result, the algorithm remains robust across slight variations in tilt, ensuring consistent performance in tasks such as line detection, object recognition, or path planning.

Robot_Camera

**System Integration Overview**

A wiring diagram and bill of materials (BOM) will be included to illustrate:

- Power distribution across all components.
- Voltage regulation.
- Microcontroller pin mapping.
- Sensor interconnections and shielding.

[Menu](#Contents)
___

## Obstacle management.
====

**Perception on Raspberry Pi 5.**

File: [📁 src](src/main_16-09-25_V3.2.0.py)

For each frame, the Pi 5 captures with Picamera2 (low-latency “preview” pipeline), then applies a horizontal Region of Interest (ROI) to reduce false positives and CPU load. The ROI is converted BGR→HSV and thresholded into color masks for red (two hue bands to cover 0/179 wrap-around) and green (one band). A 5×5 morphological opening removes speckle noise. We then extract external contours per color, keep the largest blob for each, and compute its area. Two gates are used:

MIN_CONTOUR_AREA (rejects tiny blobs/noise),

CRITICAL_CONTOUR_AREA (marks an object as immediate).
The decision layer compares red vs. green critical areas and emits a single intent byte over UART (115200): 'R' (right), 'G' (left), or 'C' (continue). The HSV design decouples color from illumination, making thresholds stable in gym lighting; ROI keeps the algorithm fast and focused.



**How vision is mixed with distance sensors (ESP32 sensor fusion).**

File: [📁 src](src/main_16-09-25_V2.2.0.py)

The camera does not command turns directly; it provides intention. The ESP32 fuses that intent with ultrasonic distances (left/right/front) inside a small state machine:

Wall-follow (PID) — default when cmd=='C' and front is clear: a PID loop (REF distance, tunable KP/KI/KD, sample time DT) adjusts the steering servo while motors run at base velocity.

Lane change — when cmd ∈ {R,G} and front is clear: apply a short speed boost, steer diagonally toward the commanded side, enforce a minimum hold time, and require a lateral distance delta (e.g., ≥9 cm) to confirm success; if the delta is not reached before a safety timeout, abort with counter-steer + short recovery and return to PID (integrator/derivative reset).

Corner / frontal obstacle — if front ≤ threshold for N consecutive samples (debounced), run a timed corner-turn routine (reverse+turn, counter-turn, recovery) and then resume PID.

Stuck vehicle detection, collision detection, and error recovery

Stuck detection (any of):
a) Kinematic timeout during lane change (no lateral delta before MAX_DURATION).
b) Sensor stagnation: left/right/front variance < ε for X cycles (robot pushing against something).
c) Optional IMU/encoders: no yaw/odometry change under drive (if available).

Collision detection: hard stop when front ≤ col_thresh, brief reverse, re-evaluate distances. Sudden lateral drop while steering hard can also trigger speed reduction and recentre.

Recovery sequence (bounded): stop → short reverse with opposite steer → check distances → short forward recovery → resume PID. If the lane-change failed, flip intended side (R↔G) once to avoid dead-locks. All recovery paths have timeouts and return deterministically to PID.

Non-trivial combinations of traffic signs

Critical-area priority + temporal hysteresis: we accept a color decision only if it exceeds the critical area and persists for M-of-N frames, which rejects distant/flickering signs.

Ties: if both colors are critical in the same window, apply a deterministic tie-break; if not critical, keep 'C'.

Safety override: a front-obstacle condition always overrides 'R'/'G'; we first handle the corner/obstacle, then resume intent processing.

Calibration notes: green can be light/pale; lower Smin/Vmin for green (HSV) if needed; use narrower H ranges or higher S/V minima to suppress false positives.

Reproducibility & tunables

Vision thresholds: HSV ranges (especially Smin/Vmin), ROI bounds, MIN_CONTOUR_AREA, CRITICAL_CONTOUR_AREA.

Control: PID gains (KP/KI/KD), sampling DT, base velocity, lane-change durations (hold/timeout), corner thresholds/debounce.

All constants are grouped near the top of each file and documented inline for on-site calibration.

**Vision & Control Parameter Table.**

| Parameter | Location (file) | Safe Min | Safe Max | Notes | Primary Impact |
|---|---|---|---|---|---|
| HSV red band 1 (min H,S,V) | vision/main_16-09-25_V3.2.0.py | (0,110,80) | (6,160,120) | Lower S/V widens detection in dim light; avoid whites/orange | Detection sensitivity |
| HSV red band 1 (max H,S,V) | vision/main_16-09-25_V3.2.0.py | (8,240,240) | (14,255,255) | Tighten H upper bound if orange/yellow leaks | False positive control |
| HSV red band 2 (min H,S,V) | vision/main_16-09-25_V3.2.0.py | (166,110,80) | (172,160,120)  | Covers hue wrap-around near 179; keep S/V above noise floor | Detection sensitivity |
| HSV red band 2 (max H,S,V) | vision/main_16-09-25_V3.2.0.py | (176,240,240)  | (179,255,255)  | High S/V helps avoid glare-driven false reds | False positive control |
| HSV green (min H,S,V) | vision/main_16-09-25_V3.2.0.py | (38,55,60) | (46,110,90) | Lower S/V for pale greens; increase if picking up lime/yellow floor | Detect pale green |
| HSV green (max H,S,V) | vision/main_16-09-25_V3.2.0.py | (75,240,240) | (90,255,255) | Narrow H to suppress yellow; keep S/V high to ignore white glare | False positive control |
| ROI x_start (px) | vision/main_16-09-25_V3.2.0.py | 20 | 120 | Start further from left edge to avoid side clutter | Latency & noise |
| ROI x_end (px) | vision/main_16-09-25_V3.2.0.py | 560 | 640 | Keep pillars centered; avoid extreme edges | Latency & noise |
| MIN_CONTOUR_AREA (px) | vision/main_16-09-25_V3.2.0.py | 350 | 900 | Higher suppresses speckles; too high may miss distant pillars | Noise / miss tradeoff |
| CRITICAL_CONTOUR_AREA (px) | vision/main_16-09-25_V3.2.0.py | 4200 | 7000 | Higher acts later (safer), lower acts earlier (aggressive) | Action timing |
| Morph kernel (opening, px) | vision/main_16-09-25_V3.2.0.py | 3 | 7 | 3 preserves faint blobs; 7 cleans heavy noise | Noise / detail tradeoff |
| UART baud (Pi→ESP32) | vision/main_16-09-25_V3.2.0.py | 57600 | 230400 | Use higher only if framing is stable | Latency / reliability |
| PID KP | controller/main_16-09-25_V2.2.0.py | 1.8 | 3.6 | Lower if oscillation; higher if sluggish | Wall-follow stability |
| PID KI | controller/main_16-09-25_V2.2.0.py | 0.00 | 0.04 | Integrates bias; too high = drift after turns | Steady-state error |
| PID KD | controller/main_16-09-25_V2.2.0.py | 0.15 | 0.45 | Damps oscillations; too high amplifies noise | Overshoot damping |
| PID DT (s) | controller/main_16-09-25_V2.2.0.py | 0.02 | 0.04 | Match loop cadence and sensor update rate | Controller timing |
| Base velocity (PWM units) | controller/main_16-09-25_V2.2.0.py | 24000 | 28500 | Higher speed reduces margin; test with front threshold | Speed vs stability |
| Boost (ΔPWM) | controller/main_16-09-25_V2.2.0.py | 800 | 1600 | Too high can skid on lane change | Lane-change success |
| Lane min hold (ms) | controller/main_16-09-25_V2.2.0.py | 150 | 260 | Guarantees diagonal onset before checking Δ | Reliability |
| Lateral delta success (cm) | controller/main_16-09-25_V2.2.0.py | 7 | 12 | Distance change required on relevant side | Success criterion |
| Lane-change timeout (ms) | controller/main_16-09-25_V2.2.0.py | 600 | 1000 | Abort if Δ not achieved; triggers recovery | Stuck detection |
| Corner front threshold (cm) | controller/main_16-09-25_V2.2.0.py | 18 | 28 | Higher = earlier/safer turn | Collision avoidance |
| Corner debounce hits (count) | controller/main_16-09-25_V2.2.0.py | 3 | 5 | Consecutive reads under threshold to avoid spurious corners | Noise immunity |
| Recovery forward (ms) | controller/main_16-09-25_V2.2.0.py | 150 | 260 | Short re-center after corner or lane abort | Re-stabilize |

**Vision RPi5.**

Obstacles1

[Menu](#Contents)
___

## Performance videos.
Our videos demonstrating our robot can be found: 

[Open Challenge](https://youtu.be/oQ5xmAe0P_g?si=DkisElCjg06YvkLW)

[Obstacle Challenge](https://youtu.be/EBErAr0Knwo?si=gBmNfuvncpcmxwht)

[Menu](#Contents)
___

## Final Remarks and future work.
====

This repository documents the full engineering journey of our team as we represented México at the Open Championship of América Finals in the Future Engineers category. From initial prototyping to final deployment, every subsystem was designed, tested, and documented with professional rigor and educational purpose.
We applied systems engineering principles, modular code design, and real-world calibration to build a solution that is not only competition ready but scalable to industrial and educational contexts. Our GitHub reflects this commitment through wiring diagrams, performance tables, and version controlled development.
Beyond the technical achievements, this journey taught us the value of teamwork, resilience, and clear communication. We thank the judges, sponsors, and WRO community for inspiring us to push boundaries and build with purpose.
This is not the end—this is a launchpad.
Our system is ready to evolve, adapt, and serve beyond the competition.

Our participation in the Open Championship of América Finals WRO Panamá 2025 marks a milestone,  but not a conclusion. The following technical directions outline how this system can evolve beyond the competition:

- Sensor Expansion: Integrate additional sensing modalities (e.g., ToF, IMU, environmental sensors) for enhanced spatial awareness and adaptive control.
- Edge AI Deployment: Implement lightweight machine learning models on device for object classification, anomaly detection, or predictive actuation.
- Industrial Adaptation: Reconfigure the system for real-world applications in local industries such as maquiladoras or logistics.
- Wireless Communication: Add ESP-NOW or MQTT protocols for multi-node coordination and remote monitoring.
- Mechanical Modularity: Design interchangeable hardware modules to support task reconfiguration without altering the system core.
- Educational Replication: Package the system as an open-source STEM kit with bilingual documentation for classroom use and community outreach.

[Menu](#Contents)
___

## References.
====

[1] Alouache A., Wu Q., "Genetic Algorithms for Trajectory Tracking of Mobile Robot Based on PID Controller". 2018 IEEE 14th International Conference on Intelligent Computer Communication and Processing (ICCP). DOI: 10.1109/ICCP.2018.8516587. IEEE. ISBN:978-1-5386-8446-7.

[2] Qi Z., Yang H., Li M., Li J., "Research on Fractional Order PID Controller in Servo Control System". 2019 IEEE 3rd Conference on Energy Internet and Energy System Integration (EI2). DOI: 10.1109/EI247390.2019.9062032. IEEE. ISBN:978-1-7281-3138-2.

[3] Luo Z., Li W., "Tracking of Mobile Robot Expert PID Controller Design and Simulation". 2014 International Symposium on Computer, Consumer and Control. IEEE.  2014 International Symposium on Computer, Consumer and Control. DOI: 10.1109/IS3C.2014.154. Electronic ISBN:978-1-4799-5277-9. 

[4] Schtchikov Y., Sokolova S., "Technical Vision for Object Recognition", 2024 International Conference on Industrial Engineering, Applications and Manufacturing (ICIEAM), DOI: 10.1109/ICIEAM60818.2024.10553791, Electronic ISBN:979-8-3503-9501-3.

[5] Ali Rospawan, Ching-Chih Tsai and Feng-Chun Tai. (2022). “Intelligent PID Temperature Control Using Output Recurrent Fuzzy Broad Learning System for Nonlinear Time-Delay Dynamic Systems”. Internacional Conference on System Science and Engineering. Electronic ISBN:978-1-6654-8852-5. 
DOI: 10.1109/ICSSE55923.2022.9948234.

[Menu](#Contents)
___

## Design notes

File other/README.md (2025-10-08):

**Digital Engineering Logbook.**
====

**February 3 – May 2, 2025:** Team Formation & Initial Prototyping

Objectives:
- Establish the core development team for the 2025 WRO season Future Engineers.
- Begin iterative testing of mechanical and software subsystems using LEGO EV3 platform.

Activities:
- Team onboarding and role assignment (mechanical, programming, documentation).
- Assembly of preliminary EV3-based robot for concept validation.
- Initial design trials:
  - Chassis stability and modularity
  - Sensor placement and cable management
- First code experiments:
  - Motor control routines (EV3 Large/Medium motors)
  - Sensor polling (ultrasonic, color, gyro)
  - Basic task automation (line following, object detection)

Outcomes:
- Functional prototype for early-stage testing
- Identification of design constraints and improvement areas

**May 3–8, 2025:** EV3 Program Testing

Focus
Software validation and refinement for LEGO EV3 platform using MicroPython.

Activities
- Executed structured tests on core program modules:
  - Motor control routines (start/stop, speed modulation)
  - Sensor polling and data handling (ultrasonic, color)
- Verified timing consistency and response accuracy under varying conditions.
- Logged performance metrics and anomalies for future optimization.
- Updated codebase with modular improvements and inline documentation.

Outcomes
- Confirmed baseline functionality of EV3 control algorithms.
- Identified edge cases requiring exception handling.

All tests conducted on LEGO EV3 hardware using MicroPython. Results documented for reproducibility and future integration.

**May 9, 2025:** Start of Final Robot Prototype Assembly

Objective
Initiate the physical construction of the final robot prototype for the 2025 WRO challenge, integrating validated subsystems and transitioning from experimental builds to competition grade architecture.

Activities
- Selected final components based on prior testing:
  - Reinforced chassis elements and modular mounts
- Assembled mechanical structure:
  - Optimized layout for sensor visibility and cable management
  - Reinforced motor mounts for stability under dynamic loads
  - Integrated modular attachments for task-specific tools
- Began integration of software modules:
  - Motor control and sensor polling routines
  - Task automation scripts adapted to final layout
  - Safety checks and exception handling

Outcomes
- Physical assembly of the final robot prototype initiated
- Mechanical and electrical subsystems aligned with competition requirements
- Codebase adapted to final hardware configuration
- Documentation updated for traceability and sponsor review

**May 12, 2025:** Completion of Final Prototype Assembly and Start of Testing
Objective
Finalize the physical assembly of the competition grade robot and initiate functional testing.
Activities
- 	Completed mechanical and electrical integration of validated subsystems
- 	Verified structural integrity and cable routing
- 	Initiated basic movement and sensor response tests
Outcomes
- 	Final prototype fully assembled
- 	Testing phase officially launched

**May 13, 2025:** Integration of L298N Driver for DC Motor Control
Objective
Enable precise motor control using the L298N H bridge driver.
Activities
- 	Connected L298N to motor and microcontroller
- 	Verified directional control and voltage levels
- 	Conducted initial movement tests
Outcomes
- 	L298N driver successfully integrated and verified

**May 19, 2025:** Evaluation of VL53L0X Distance Sensor
Objective
Assess the VL53L0X sensor for short-range distance measurement.
Activities
- 	Mounted sensor and ran calibration routines
- 	Measured response time and accuracy
- 	Compared readings across surface types
Outcomes
- 	Sensor performance evaluated for short-range use

**May 21, 2025:** Servo Motor Installation for Steering Control
Objective
Implement steering mechanism using servo motor.
Activities
- 	Installed servo motor on robotic platform
- 	Conducted range-of-motion tests
- 	Verified responsiveness to control signals
Outcomes
- 	Steering system operational with servo motor

**May 26, 2025:** Initial PWM Test for Speed Control
Objective
Test pulse width modulation for motor speed regulation.
Activities
- 	Configured PWM output from microcontroller
- 	Applied varying duty cycles to motor
- 	Monitored speed response and stability
Outcomes
- 	PWM control validated for speed modulation

**May 27, 2025:** PWM and Servo Synchronization
Objective
Synchronize PWM motor control with servo steering.
Activities
- 	Integrated PWM with L298N driver
- 	Coordinated servo and motor routines
- 	Conducted dynamic movement tests
Outcomes
- 	Synchronized control system operational

**June 2, 2025:** VL53L0X Sensor Integration into Main Program
Objective
Enable continuous distance measurement in core software.
Activities
- 	Embedded sensor polling into main loop
- 	Implemented data filtering and exception handling
- 	Verified real time readings
Outcomes
- 	VL53L0X sensor integrated into robot logic

**June 10, 2025:** Calibration of VL53L0X and Servo Motor
Objective
Fine tune sensor and steering parameters.
Activities
- 	Adjusted sensor thresholds and servo angles
- 	Conducted test runs on base structure
- 	Logged performance metrics
Outcomes
- 	Sensor and servo calibrated for reliable operation

**June 16, 2025:** TCS34725 Sensor Calibration for Color Detection
Objective
Optimize color detection for track recognition.
Activities
- 	Tuned gain and integration time parameters
- 	Tested detection of blue and orange stripes
- 	Logged RGB values for reference
Outcomes
- 	Color sensor calibrated for track conditions

**June 23, 2025:** PID and Distance Measurement Integration
Objective
Combine distance sensing with PID control logic.
Activities
- 	Merged VL53L0X readings with PID routines
- 	Tested response to varying distances
- 	Adjusted PID coefficients
Outcomes
- 	Distance based PID control implemented

**June 30, 2025:** First Program with TCS34725 for Track Detection
Objective
Detect track colors to determine robot course.
Activities
- 	Programmed sensor to identify blue and orange
- 	Mapped color readings to navigation decisions
- 	Conducted initial trials
Outcomes
- 	Track detection logic implemented

**July 1, 2025:** Color Detection Limitations Identified
Objective
Evaluate sensor performance under challenge conditions.
Activities
- 	Tested color detection at competition speed
- 	Logged missed detections and delays
Outcomes
- 	TCS34725 deemed unreliable at high speed

**July 7, 2025:** Replacement of VL53L0X with Ultrasonic Sensor
Objective
Improve distance measurement accuracy.
Activities
- 	Installed ultrasonic sensor
- 	Developed new distance measurement program
- 	Verified sensor response
Outcomes
- 	Ultrasonic sensor adopted for distance sensing

**July 11, 2025:** Hitechnic Sensor Evaluation
Objective
Detect track sections and stopping points.
Activities
- 	Tested detection of blue/orange stripes
- 	Evaluated sensor response at speed
Outcomes
- 	Sensor discarded due to unreliable detection

**July 14–20, 2025:** Structural Component Design and Installation
Objective
Design and install custom mounts for electronics and camera.
Activities
- 	Designed and printed:
- 	Main base (base_principal_v6.stl)
- 	Connector base (base_conector_v3.stl)
- 	Raspberry Pi 5 base (base_pi_5_v5.stl)
- 	Camera base (base_camera_v2.stl)
- 	Camera support (base-Camera-U2.stl)
- 	Camera cover (tapa-Camera.stl)
- 	Mounted components on robot frame
Outcomes
- 	Structural integration of electronics and camera completed
- 	VL53L0X sensor permanently discarded

**July 27–28, 2025:** Camera Configuration and Sensor Integration
Objective
Enable visual processing and sensor communication.
Activities
- 	Configured Pi5 camera for continuous capture
- 	Integrated CV2 for image workflow
- 	Soldered URM37 cables
- 	Verified UART communication
- 	Installed start button
Outcomes
- 	Visual and sensor systems operational

**July 30–31, 2025:** Ultrasonic Sensor Mount and Positioning Program
Objective
Support and utilize ultrasonic sensors for navigation.
Activities
- 	Designed and installed base_urm37_v7.STL
- 	Created program to determine robot position
Outcomes
- 	Position tracking logic implemented

**August 1–2, 2025:** Rotation Sensing and Base Support
Objective
Enable rotation tracking and structural support.
Activities
- 	Read rotation using MPU6050
- 	Applied discrete PID formulas
- 	Designed and printed base_robot_v2.STL
Outcomes
- 	Rotation sensing and support structure completed

**August 4–8, 2025:** Sensor Testing and PID Tuning
Objective
Evaluate alternative sensors and finalize control logic.
Activities
- 	Tested Gy-521 and AS5600 sensors
- 	Discarded AS5600 due to poor performance
- 	Finalized PID tuning
- 	Added BTS7960 driver
- 	Chose ultrasonic sensor for rotation control
Outcomes
- 	PID and sensor configuration finalized

**August 10, 2025:** Challenge 1 Testing and Magnetometer Evaluation
Objective
Complete first challenge and test orientation sensing.
Activities
- 	Ran full challenge simulation
- 	Tested magnetometer for start direction
Outcomes
- 	Magnetometer discarded due to poor accuracy

**August 15–18, 2025:** Image Processing Optimization
Objective
Enable real-time image analysis for block detection.
Activities
- 	Implemented RGB conversion and segmentation
- 	Integrated Cu2 with Pi5
- 	Used NumPy for matrix operations and histogram analysis
- 	Documented use cases in scripts
Outcomes
- 	Image processing routines optimized and validated

**August 23, 2025:** PID Control Adjustments
Objective
Refine navigation control.
Activities
- 	Adjusted PID parameters based on test results
- 	Verified smoother trajectory
Outcomes
- 	Navigation control improved

**August 24–30, 2025:** Challenge Trial Period
Objective
Conduct full challenge simulations.
Activities
- 	Ran repeated trials for both challenges
- 	Logged performance and failure points
Outcomes
- 	Trial data collected for final tuning

**August 30, 2025:** Servo Motor Replacement and Recalibration
Objective
Restore steering functionality.
Activities
- 	Replaced broken servo motor
- 	Recalibrated angles and control parameters
Outcomes
- 	Steering system restored and recalibrated

**September 1–13, 2025:** Technical Documentation Finalization and Software Calibration
Objective
Prepare the system and documentation for the National WRO Competition in Rosarito, Baja California (September 19–20, 2025).
Activities
- Finalized technical documentation, including:
- System architecture overview (hardware/software)
- Wiring diagrams and BOM (Bill of Materials)
- Integrated performance graphs and comparative tables for motor and sensor analysis
- Refined Markdown structure for GitHub repository clarity and sponsor readability
- Calibrated control algorithms for servo response:
- Tuned PID parameters for smoother actuation
- Adjusted PWM ranges
- Conducted functional tests to validate sensor feedback and actuation timing
Outcomes
- Documentation ready for national level technical review
- Software tuned for reliable performance under competition conditions
- GitHub repository updated, sponsor ready materials

**October 1–13, 2025:** Software Refinement and Technical Content Preparation
Objective
Finalize program logic and documentation for the WRO Future Engineers challenges.
Activities
- Refactored control algorithms for improved task execution
- Validated sensor feedback loops
- Logged test data for threshold tuning and environmental adaptation
- Prepared technical content for GitHub
- Added wiring diagrams, flowcharts, and performance tables
- Conducted dry runs of Future Engineers challenge scenarios
- Verified timing, accuracy, and recovery logic under simulated conditions
Outcomes
- Program logic optimized for challenge execution
- GitHub repository updated with sponsor ready technical documentation
- System validated for competition deployment

[Principal README](https://github.com/CICSA-NET/WRO2025-CICSA/blob/main/README.md)
___

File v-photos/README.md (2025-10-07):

Vehicle's photos
====

This directory must contain  photos of the vehicle (from every side, from top and bottom).

[It also includes the first prototype built with LEGO, used for initial testing.](/v-photos/Robot_lego.jpeg)

[Menu](https://github.com/CICSA-NET/WRO2025-CICSA/blob/main/README.md)
___

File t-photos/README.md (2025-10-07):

Team's photos
====

This directory contain 2 photos of the team (an official one and one funny photo with all team members)



[Menu](https://github.com/CICSA-NET/WRO2025-CICSA/blob/main/README.md)
___

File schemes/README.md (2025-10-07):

Electromechanical diagrams
====

This directory contain schematic diagrams of the electromechanical components illustrating all the elements (electronic components and motors) used in the vehicle and how they connect to each other.

[Menu](https://github.com/CICSA-NET/WRO2025-CICSA/blob/main/README.md)
___

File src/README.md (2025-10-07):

Control software
====

This directory contain code for control software which is used by the vehicle to participate in the competition and which was developed by the participants.

## Version History

### pid_esp.py – First version of the code (ESP-32).
- Basic sensor integration (vl53l0x) with ESP32 using MicroPython
- Modular code structure with functions.
- Basic error handling.

### mainDef15-08_V1.1.0.py – Sensor Expansion and PID control (ESP-32).
- Added support for URM37 sensors.
- Improved abstraction and reusable modules.
- Implemented PID control for steering.
- Real-time PID parameter adjustment.
- Improved trajectory stability and response time.

### main_10_09_25_V1.2.0.py – Final release free challenge (ESP-32).
- Improvements were added to the startup routine to detect which direction to turn.

### main_10_09_25_V1.3.0.py – Final release free challenge (ESP-32).
- Final Program with comments.

### main_16_09-25_V2.1.0 – Final release challenge obstacles (ESP-32).
- This code is for the ESP-32 in charge of carrying out the obstacle course, it communicates via serial with the Raspberry Pi 5,   receives commands to control the robot, and contains a PID to navigate the track.

### main_16-09-25_V2.2.0.py – Final release challenge obstacles (ESP-32).
- Final Program with comments.

### main_16-09-25_V3.1.0.py – Final release challenge obstacles (Raspberry Pi 5).
- This is the main code installed on the Raspberry Pi 5, which contains the cv2, numpy, serial, time, and picamera2 libraries. To detect obstacles, it communicates with the ESP-32 to control the robot.

### main_16-09-25_V3.2.0.py – Final release challenge obstacles (Raspberry Pi 5).
- Final Program with comments.

[Menu](https://github.com/CICSA-NET/WRO2025-CICSA/blob/main/README.md)
___

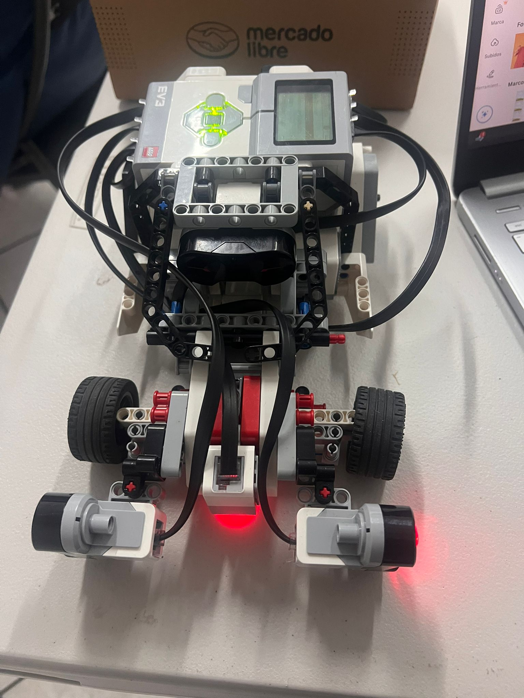
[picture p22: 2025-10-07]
v-photos/Robot_lego.jpeg

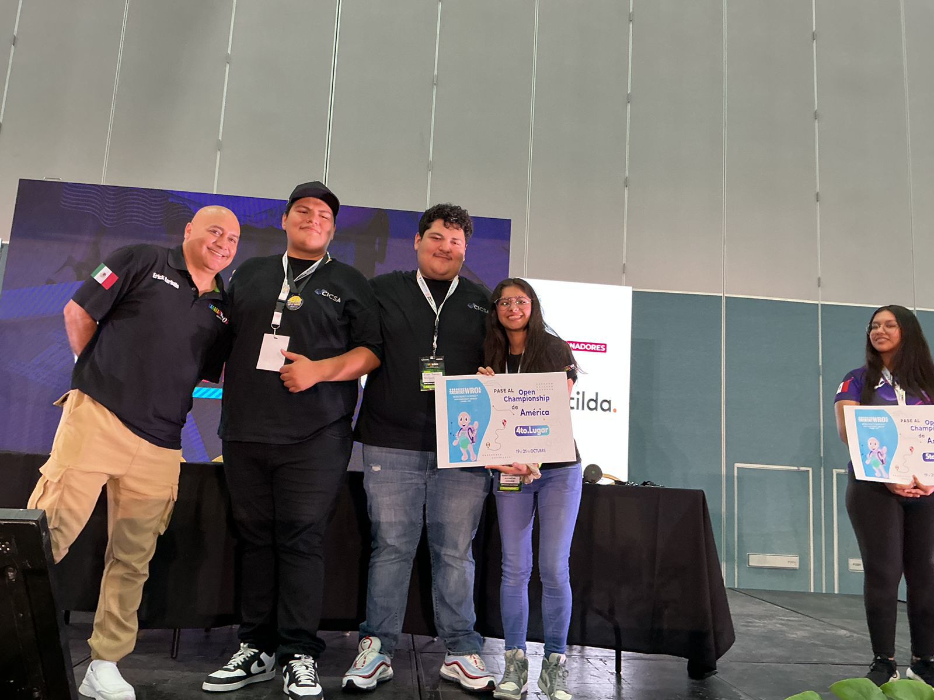
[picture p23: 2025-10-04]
t-photos/team4.jpeg

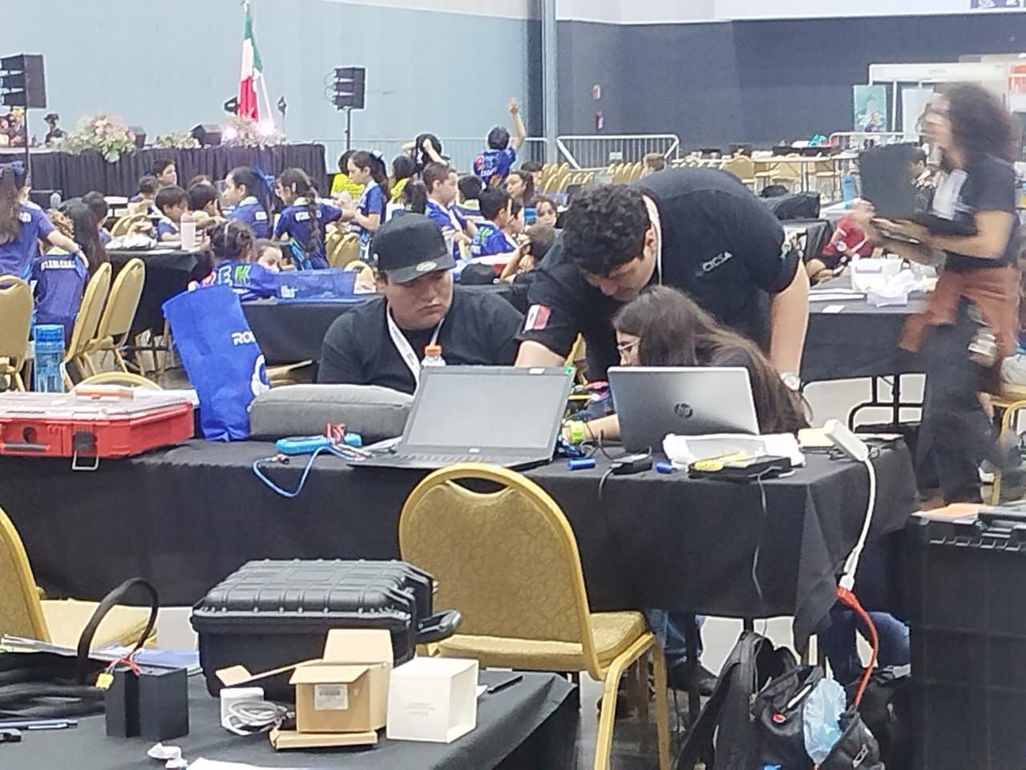
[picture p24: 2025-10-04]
t-photos/Team3.jpeg

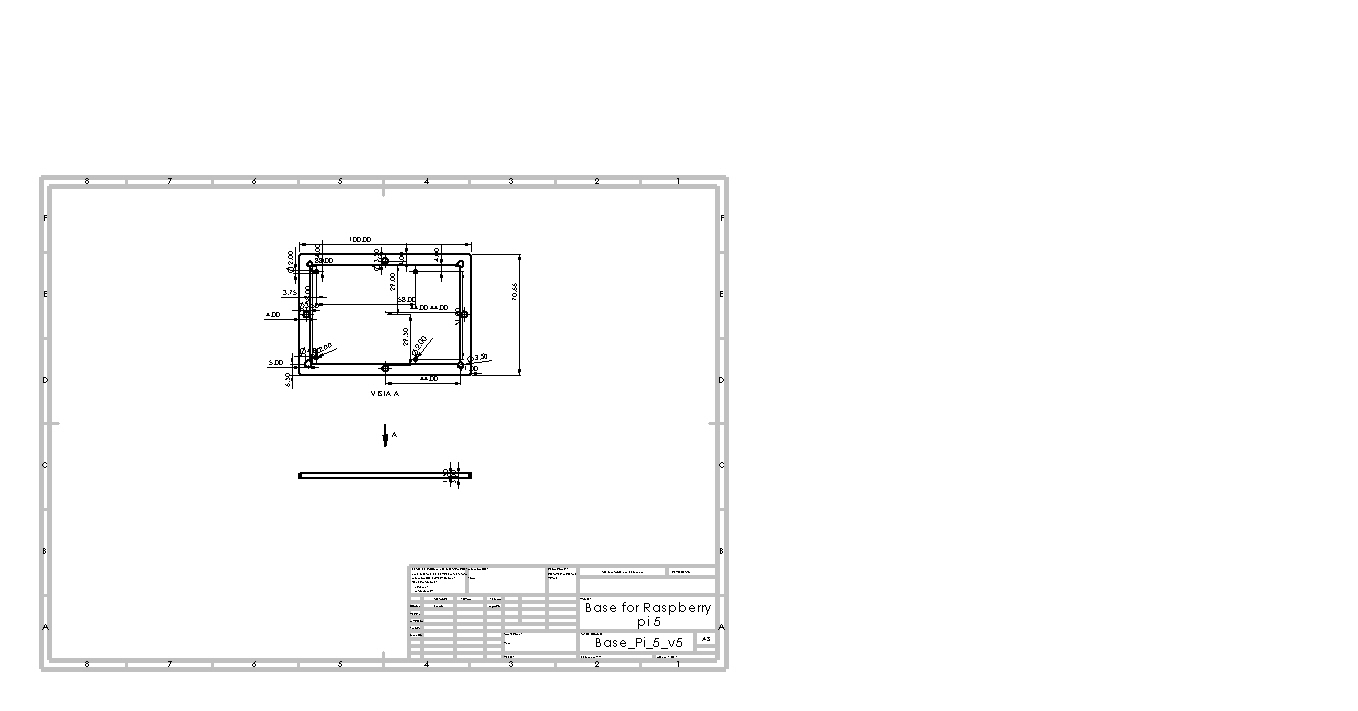
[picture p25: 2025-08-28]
models/Base_Pi_5_v5.JPG

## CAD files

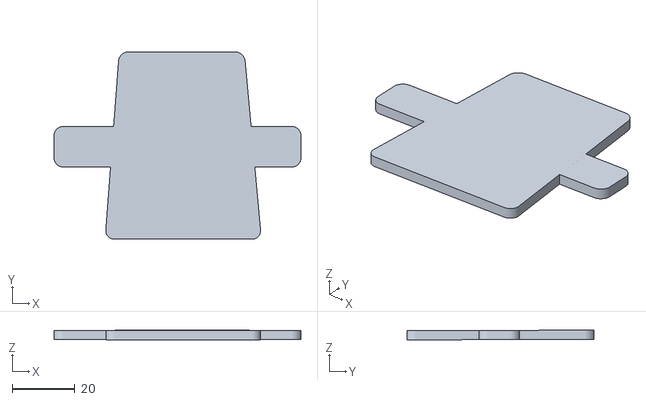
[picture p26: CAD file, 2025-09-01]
models/base_l298n.stl
79.0 x 60.0 x 3.09

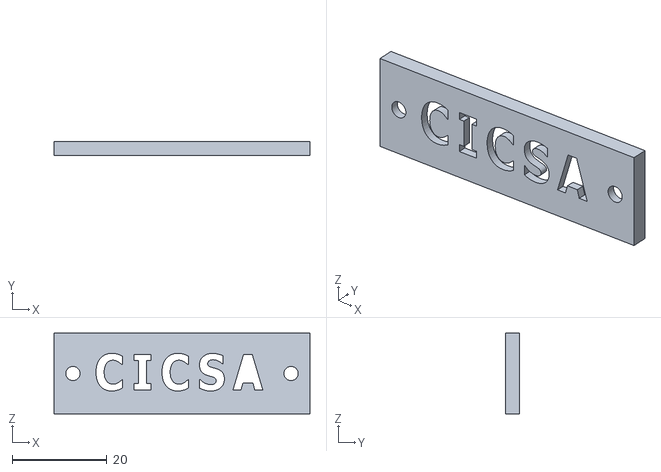
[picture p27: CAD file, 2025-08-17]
models/tapa_camera.STL
54.0 x 3.00 x 17.0

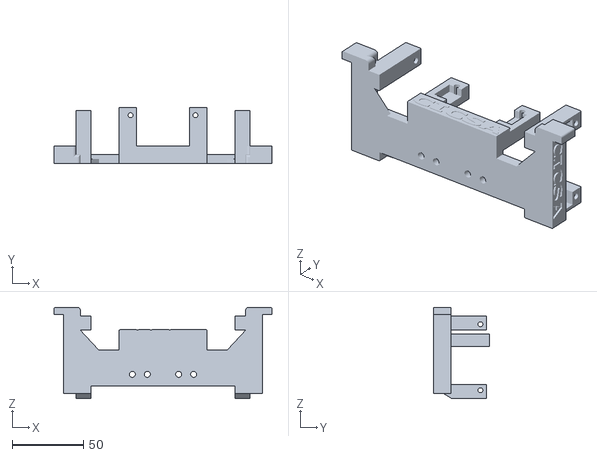
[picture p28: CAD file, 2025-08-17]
models/base_urm37_v7.STL
153.0 x 39.0 x 64.0

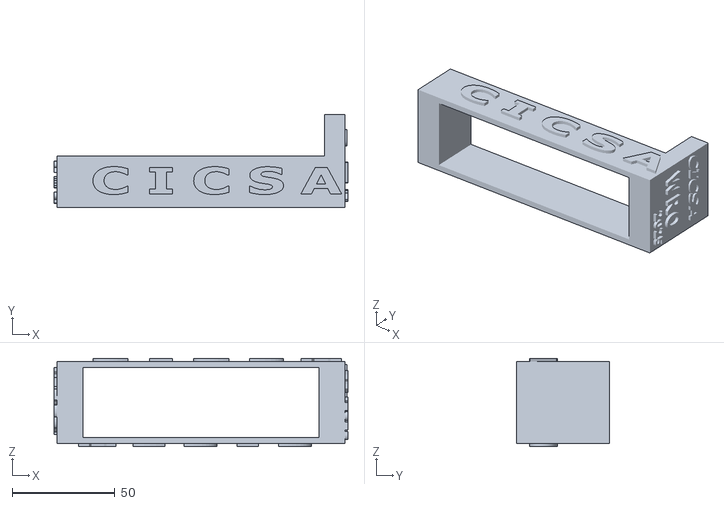
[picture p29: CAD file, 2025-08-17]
models/base_robot_V2.STL
143.0 x 45.0 x 43.0

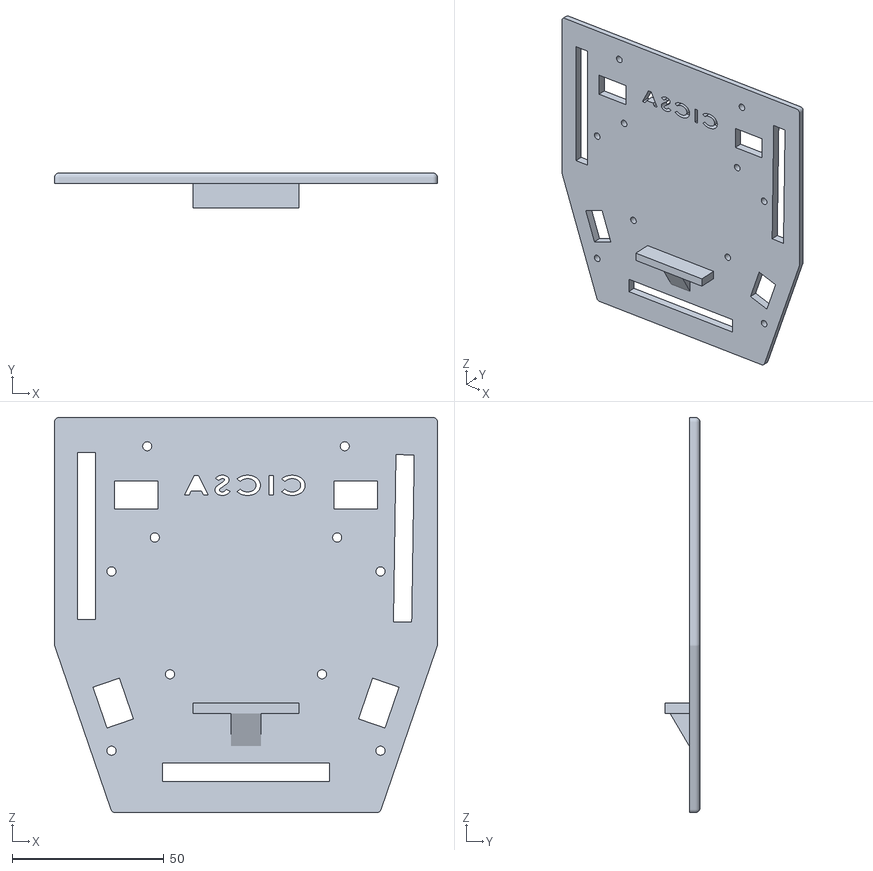
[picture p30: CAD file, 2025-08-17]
models/base_principal_V6.STL
126.0 x 11.5 x 130.0

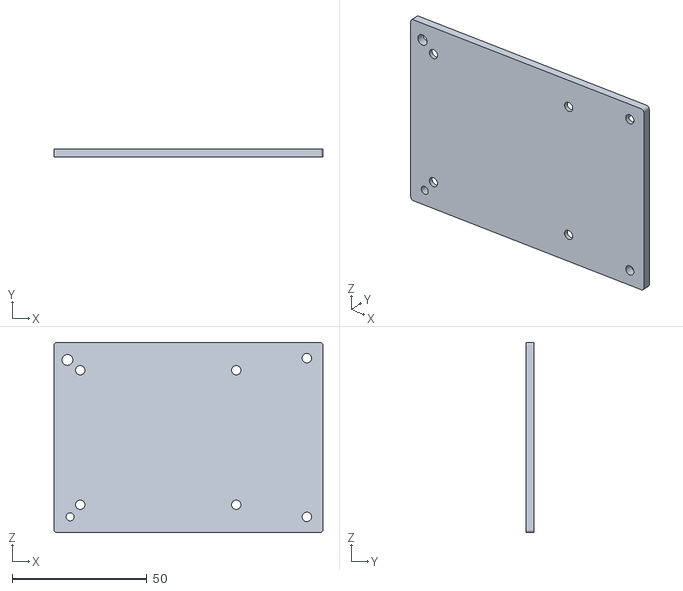
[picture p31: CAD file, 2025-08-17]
models/Base_Pi_5_v5.STL
100.0 x 3.00 x 70.7

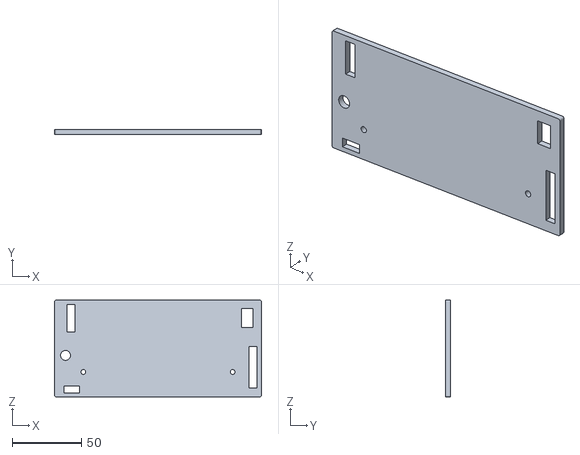
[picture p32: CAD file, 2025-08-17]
models/base_conector_v3.STL
150.0 x 3.50 x 70.0

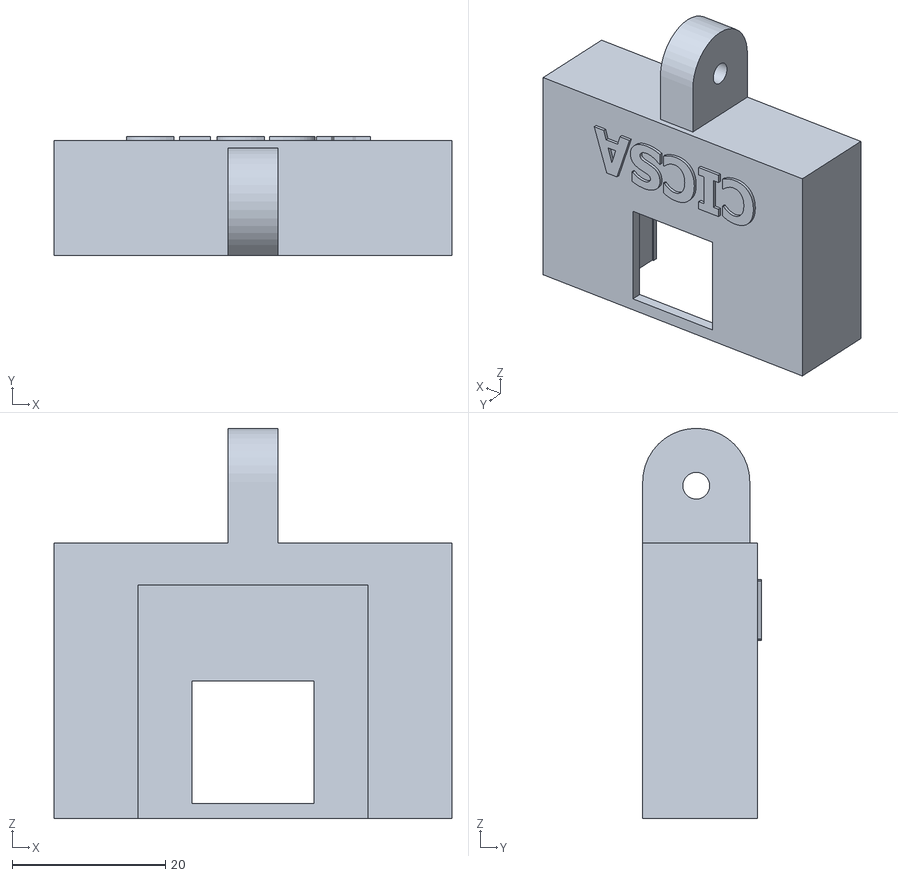
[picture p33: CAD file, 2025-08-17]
models/base_camera2_V2.STL
52.0 x 15.5 x 51.0

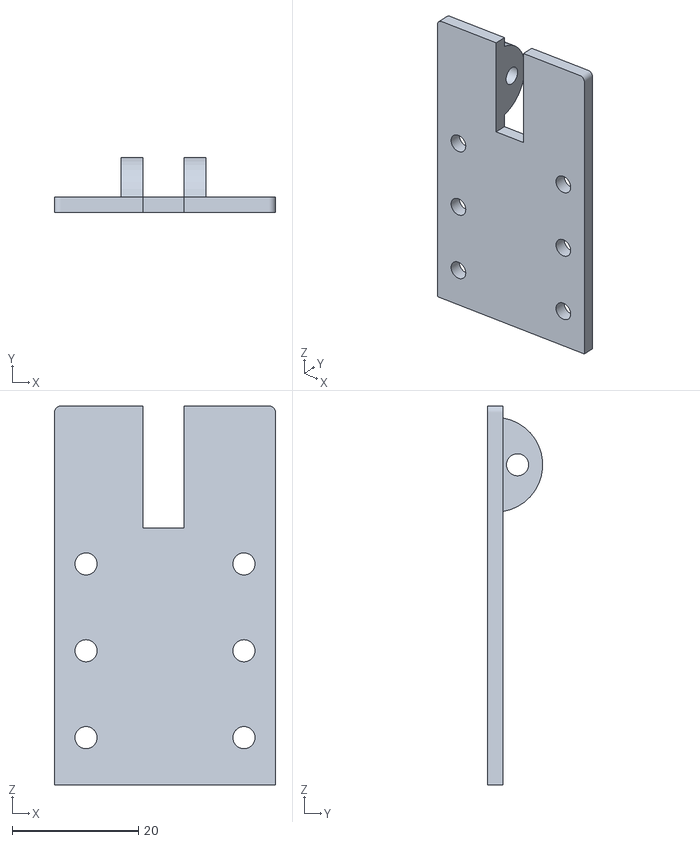
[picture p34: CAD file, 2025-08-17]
models/base_camera_v2.STL
35.0 x 8.72 x 60.0

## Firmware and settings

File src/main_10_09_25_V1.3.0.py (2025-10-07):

# ============================================================
# Authors: Xiara Alcantar, Iván Hernández & Sergio Hernández
# Date: September 17, 2025
# Description:
#     This program was developed for the Open Challenge
#     of the Future Engineers category at the WRO 2025 National Stage.
# Version: 1.3.0
# ============================================================

import _thread
from machine import Pin, I2C, PWM, time_pulse_us
import time
from time import sleep_ms

# --- Globlal Variables ---
distance_left = 0
distance_right = 0
distance_front = 0
CENTER = 43      #48
LEFT = 20        #25
RIGHT = 60       #68

#determine turn
direction = ""
velocity = 30000                                                          

# --- Pin configuration and main modules ---
servo = PWM(Pin(5), freq=50) # Servo motor
servo.duty(CENTER)
time.sleep_ms(500)
led = Pin(2, Pin.OUT)                   # LED 
led.value(1)
time.sleep(0.25)
led.value(0)

in1 = Pin(18, Pin.OUT)                  # Motor IN1
in2 = Pin(19, Pin.OUT)                  # Motor IN2
enable = PWM(Pin(23), freq=1000)        # Motor PWM enable
enable.duty_u16(0)

# --- sensors ---
UR_ECHO_LEFT = Pin(15, Pin.IN)   
UR_TRIG_LEFT = Pin(4, Pin.OUT)
UR_ECHO_RIGHT = Pin(32, Pin.IN)   
UR_TRIG_RIGHT = Pin(33, Pin.OUT)
UR_ECHO_FRONT = Pin(27, Pin.IN)
UR_TRIG_FRONT = Pin(14, Pin.OUT)      
UR_TRIG_LEFT.on()                  
time.sleep_ms(500)
UR_TRIG_RIGHT.on()                  
time.sleep_ms(500)
UR_TRIG_FRONT.on()
time.sleep_ms(500)

# --- sw ---
button = Pin(13, Pin.IN, Pin.PULL_UP)

# --- Functions ---
# turn around
def turn_servo(value):
    for i in range(3):
        servo.duty(value)
        time.sleep_us(100)
        
# Get data from distance sensors
def get_distance(echo, trig):
    trig.off()
    time.sleep_us(10)
    trig.on()
    low_time = time_pulse_us(echo, 0, 100000)
    if low_time <= 0 or low_time > 100000:
        return None
    else:
        return int(low_time // 50)  # cada 50 µs ≈ 1 cm
        
# Get data from distance sensors
def get_data():
    global distance_left
    global distance_right
    global distance_front

    while True:     
        distance_front = get_distance(UR_ECHO_FRONT, UR_TRIG_FRONT) 
        time.sleep_ms(5)
        distance_right = get_distance(UR_ECHO_RIGHT, UR_TRIG_RIGHT)
        time.sleep_ms(5)
        distance_left = get_distance(UR_ECHO_LEFT, UR_TRIG_LEFT)
        time.sleep_ms(5)
        
# turn around      
def turn_robot():
    global direction
    global distance_front
    global velocity
    global CENTER
    global LEFT
    global RIGHT
    
    if direction == "right":
        servo.duty(LEFT)  # left
        for i in range(22):   
            servo.duty(LEFT)
            enable.duty_u16(velocity + 8000)
            time.sleep(0.001)
        
    if direction == "left":
        servo.duty(RIGHT)  # right
        for i in range(23):    
            servo.duty(RIGHT) 
            enable.duty_u16(velocity + 8000)
            time.sleep(0.001)
    turn_servo(CENTER)   # center
    time.sleep(0.1)
    
# Start, identify meaning.
def start_robot():
    global distance_left
    global distance_right
    global direction
    global distance_front
    global velocity
    global CENTER
    global LEFT
    global RIGHT
    flag_direction = False
    
    in1.off()
    in2.on()
    enable.duty_u16(45000)
    time.sleep(0.35)
    enable.duty_u16(velocity - 6000)
    
    while not flag_direction:
        time.sleep(0.01)
        if distance_left > 100:
            direction = "right" # counterclockwise
            if distance_front > 60 and flag_direction == False :
                time.sleep(0.25)
                flag_direction = True
                servo.duty(LEFT)  # left
                enable.duty_u16(velocity + 10000) 
                for i in range(22):    #Ajustar valor dependiendo del sensor
                    servo.duty(LEFT)  # Giro a la izquierda
                    time.sleep(0.001)
                 
            if distance_front < 60 and flag_direction == False :
                flag_direction = True
                enable.duty_u16(0)
                time.sleep(0.2)
                in1.on()
                in2.off()
                while True:
                    enable.duty_u16(velocity)
                    if distance_front >= 55:
                        break
                    time.sleep(0.001)
                enable.duty_u16(0)
                time.sleep(0.2)
                in1.off()
                in2.on()
                enable.duty_u16(velocity)
                time.sleep(0.85)
                enable.duty_u16(velocity + 10000)
                for i in range(33):
                    time.sleep(0.001)
                    servo.duty(LEFT)  # left
                    
        #******************************************************       
        elif distance_right > 100:
            direction = "left" # clockwise
            if distance_front > 60 and flag_direction == False :
                time.sleep(0.25)
                flag_direction = True
                servo.duty(RIGHT)  # right
                enable.duty_u16(velocity + 10000)
                for i in range(22):  
                    servo.duty(RIGHT)  # right
                    time.sleep(0.001)
                
            if distance_front < 60 and flag_direction == False :
                flag_direction = True
                enable.duty_u16(0)
                time.sleep(0.1)
                in1.on()
                in2.off()
                while True:
                    enable.duty_u16(velocity)
                    if distance_front >= 55:
                        break
                    time.sleep(0.001)
                enable.duty_u16(0)
                time.sleep(0.2)
                in1.off()
                in2.on()
                enable.duty_u16(velocity)
                time.sleep(0.85)
                enable.duty_u16(velocity + 10000)
                for i in range(33):
                    time.sleep(0.001)
                    servo.duty(RIGHT)  # right
                    
    turn_servo(CENTER)   # center
    time.sleep(0.15)

# --- PID control algorithm ---
def pid(ref, condition, vel, sensor):
    global distance_left
    global distance_right
    global distance_front
    global CENTER
    global LEFT
    global RIGHT
    flag_ref=False
    output = 0.0
    error = 0.0
    p_error_2 = 0.0
    kp = 1.4        
    ki = 0.01
    kd = 0.25
    T = 0.015
    p_output = 0.0
    count = 0
    p_error = 0.0

    led.value(1)
    in1.off()
    in2.on()
    
#     Start the control algorithm
    enable.duty_u16(vel)
    while count <= condition:
        p_error_2 = p_error
        p_error = error
        if sensor == "left":
            input_sensor = distance_left
            error = input_sensor - ref
        elif sensor == "right":
            input_sensor = distance_right
            error = ref - input_sensor
        output = int(kp * (error - p_error) + ki * error + kd * (error - (2 * p_error) + p_error_2) + p_output)
        duty = CENTER - output
        duty = min(max(duty, LEFT), RIGHT)
        servo.duty(duty)
        p_output = output
        count += 1
        time.sleep(T)
        
        if condition == 10000 and distance_front <= 73 and count >= 15:
            break
        
    turn_servo(CENTER)   # center
    led.value(0)
    
#---------------------------------------- main -----------------------------------------
_thread.start_new_thread(get_data, ())
time.sleep(1.5)

# Wait start
led.value(1)
while button.value() != 0:
    time.sleep(0.1)
led.value(0)
# Main program
try:
    start_robot()
    #pid(25, 10000, velocity, direction)
    #turn_robot()
    for i in range(3):
        pid(25, 10000, velocity, direction)
        turn_robot()
    if direction == "right":
        pid(30, 4, velocity, direction)
        #turn_servo(LEFT)
    if direction == "left":
        pid(30, 5, velocity, direction)
        #turn_servo(RIGHT)

    enable.duty_u16(0)
    time.sleep(1)
    turn_servo(CENTER)   # Center
    
except KeyboardInterrupt:
    turn_servo(CENTER)   # Center

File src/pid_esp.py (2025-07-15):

import _thread
from machine import Pin, PWM, I2C
from time import sleep
from vl53l0x import VL53L0X

# --- Configuración de pines y módulos principales ---
servo = PWM(Pin(5), freq=50)            # Servo motor
led = Pin(2, Pin.OUT)                   # LED interno
led.value(1)
sleep(0.25)
led.value(0)

in1 = Pin(18, Pin.OUT)                  # Motor IN1
in2 = Pin(19, Pin.OUT)                  # Motor IN2
enable = PWM(Pin(21), freq=1000)        # Motor PWM enable

# --- Buses I2C para sensores VL53L0X ---
i2c_left = I2C(1, sda=Pin(32), scl=Pin(33), freq=100000)   # Sensor izquierdo
i2c_right = I2C(0, sda=Pin(25), scl=Pin(26), freq=100000)  # Sensor derecho

vl53_left = VL53L0X(i2c_left)
vl53_right = VL53L0X(i2c_right)

# --- Función de lectura de sensores VL53L0X ---
def leer_sensores():
    distancia_izq = int(vl53_left.ping())
    distancia_der = int(vl53_right.ping())
    if distancia_izq < 200:
        return "left"
    elif distancia_der < 200:
        return "right"
    else:
        return "ninguno"

# --- Algoritmo PID para ajuste de movimiento ---
def pid(ref, condicion, vel, sensor):
    output = 0.0
    error = 0.0
    p_error_2 = 0.0
    kp = 30
    ki = 0.1
    kd = 6.3
    T = 0.01
    p_output = 0.0
    count = 0
    p_error = 0.0

    # Activar motor con aceleración progresiva
    for d in range(400, int(vel / 65535 * 1023), 100):
        enable.duty(d)
        sleep(0.05)

    in1.off()       # Ajusta dirección si tu robot retrocede
    in2.on()

    while count <= condicion:
        p_error_2 = p_error
        p_error = error
        if sensor == "left":
            input_sensor = int(vl53_left.ping())
            error = input_sensor - ref
        elif sensor == "right":
            input_sensor = int(vl53_right.ping())
            error = ref - input_sensor
        else:
            input_sensor = ref

        output = int(kp * (error - p_error) + ki * error + kd * (error - (2 * p_error) + p_error_2) + p_output)
        duty = 6650 - output
        duty = min(max(duty, 4750), 7850)
        servo.duty(int(duty / 65535 * 1023))  # Conversión PWM para ESP32

        p_output = output
        count += 1
        sleep(T)

    enable.duty(0)
    servo.duty(int(6650 / 65535 * 1023))

# --- Programa principal ---
try:
    led.value(1)
    servo.duty(int(6650 / 65535 * 1023))
    sleep(1.5)

    sensor_detectado = leer_sensores()
    if sensor_detectado in ["left", "right"]:
        pid(250, 250, 40000, sensor_detectado)  # Máxima potencia segura

    enable.duty(0)
    servo.duty(int(6650 / 65535 * 1023))
    led.value(0)

except KeyboardInterrupt:
    print("Fin")

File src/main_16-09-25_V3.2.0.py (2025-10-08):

# Authors: Iván Hernández, Sergio Hernández & Xiara Alcantar
# Date: September 17, 2025
# Description: This program was developed for the Raspberry Pi 5
#              to execute the obstacle challenge in the Future Engineers
#              category of the WRO 2025 National Stage.
# Target Platform: Raspberry Pi 5 (64-bit, Debian-based OS)
# Language: Python 3.11
# Interfaces: GPIO (PWM, Digital I/O), UART (Serial)
# Sensors: 3x URM37 V5.0 Ultrasonic Sensors (PWM mode)
# Motor Control: Dual H-Bridge (L298N or equivalent)
# Version: 3.2.0

import cv2
import numpy as np
import serial
import time
from picamera2 import Picamera2

MIN_CONTOUR_AREA = 500
CRITICAL_CONTOUR_AREA = 4800

# --- CONFIGURATIONS ---
SERIAL_PORT = '/dev/ttyUSB0'
BAUDRATE = 115200
ser = None
lower_red1 = np.array([0, 120, 90])
upper_red1 = np.array([10, 255, 255])
lower_red2 = np.array([170, 120, 90])
upper_red2 = np.array([179, 255, 255])
lower_green = np.array([40, 80, 80])
upper_green = np.array([85, 255, 255])


# --- INITIALIZATION ---
try:
    ser = serial.Serial(SERIAL_PORT, BAUDRATE, timeout=0.1)
    print(f"Serial Port {SERIAL_PORT} open.")
except serial.SerialException as e:
    print(f"WARNING: Failed to open serial port: {e}")

print("Initializing camera using PREVIEW configuration...")
picam2 = Picamera2()
camera_config = picam2.create_preview_configuration()
picam2.configure(camera_config)
picam2.start()
print("Camera successfully initialized.")
time.sleep(1.0)

frame_test = picam2.capture_array()
FRAME_HEIGHT, FRAME_WIDTH, _ = frame_test.shape

roi_start_x = 40
roi_end_x = 600
roi_start_y = 0 
roi_end_y = FRAME_HEIGHT
print(f"Detected frame: {FRAME_WIDTH}x{FRAME_HEIGHT}. Using ROI in x:({roi_start_x}, {roi_end_x})")
print("Press 'q' in the camera window to exit.")

# --- MAIN LOOP ---
while True:
    # Capture a raw frame from the PiCamera2
    frame_raw = picam2.capture_array()
    
    # Convert the frame from RGB to BGR format (OpenCV uses BGR by default)
    frame = cv2.cvtColor(frame_raw, cv2.COLOR_RGB2BGR)
    
    # Draw a rectangle to visualize the Region of Interest (ROI)
    cv2.rectangle(frame, (roi_start_x, roi_start_y), (roi_end_x, roi_end_y), (255, 255, 0), 2)
    
    # Extract the ROI from the frame for color analysis
    roi = frame[roi_start_y:roi_end_y, roi_start_x:roi_end_x]
    
    # Convert the ROI from BGR to HSV color space for better color segmentation
    hsv = cv2.cvtColor(roi, cv2.COLOR_BGR2HSV)
    
    # Create two masks to detect red color ranges (to cover hue wrap-around)
    mask_red1 = cv2.inRange(hsv, lower_red1, upper_red1)
    mask_red2 = cv2.inRange(hsv, lower_red2, upper_red2)
    
    # Combine both red masks into a single binary mask
    mask_red = cv2.bitwise_or(mask_red1, mask_red2)
    
    # Create a mask to detect green color range
    mask_green = cv2.inRange(hsv, lower_green, upper_green)
    
    # Define a kernel for morphological operations (noise reduction)
    kernel = np.ones((5, 5), np.uint8)
    
    # Apply morphological opening to clean up the red mask
    mask_red = cv2.morphologyEx(mask_red, cv2.MORPH_OPEN, kernel)
    
    # Apply morphological opening to clean up the green mask
    mask_green = cv2.morphologyEx(mask_green, cv2.MORPH_OPEN, kernel)
    
    # Find contours in the red mask (external shapes only)
    contours_red, _ = cv2.findContours(mask_red, cv2.RETR_EXTERNAL, cv2.CHAIN_APPROX_SIMPLE)
    
    # Find contours in the green mask (external shapes only)
    contours_green, _ = cv2.findContours(mask_green, cv2.RETR_EXTERNAL, cv2.CHAIN_APPROX_SIMPLE)

    # Initialize variables to track the critical area (in pixels) occupied by red and green objects
    red_critical_area = 0
    green_critical_area = 0

    # 1. Analyze red contours
    if contours_red:
        # Identify the largest red contour based on area
        largest_red_contour = max(contours_red, key=cv2.contourArea)
        red_area = cv2.contourArea(largest_red_contour)
    
        # Proceed only if the red contour is minimally visible
        if red_area > MIN_CONTOUR_AREA:
            # Draw a bounding box around the red pillar (obstacle)
            x, y, w, h = cv2.boundingRect(largest_red_contour)
            cv2.rectangle(frame, (x + roi_start_x, y), (x + roi_start_x + w, y + h), (0, 0, 255), 2)
    
            # Store its area only if it qualifies as a CRITICAL threat
            if red_area > CRITICAL_CONTOUR_AREA:
                red_critical_area = red_area
    # 2. Analyze green contours
    if contours_green:
        # Identify the largest green contour based on area
        largest_green_contour = max(contours_green, key=cv2.contourArea)
        green_area = cv2.contourArea(largest_green_contour)

        # Proceed only if the green contour is minimally visible
        if green_area > MIN_CONTOUR_AREA:
            # Draw a bounding box around the green pillar (obstacle)
            x, y, w, h = cv2.boundingRect(largest_green_contour)
            cv2.rectangle(frame, (x + roi_start_x, y), (x + roi_start_x + w, y + h), (0, 255, 0), 2)

            # Store its area only if it qualifies as a CRITICAL threat
            if green_area > CRITICAL_CONTOUR_AREA:
                green_critical_area = green_area
    # 3. Compare critical areas and make the final decision
    command_to_send = 'C'  # Default command (e.g., continue or no threat detected)

    if red_critical_area > green_critical_area:
        command_to_send = 'R'  # Red obstacle is dominant — take red avoidance action
    elif green_critical_area > red_critical_area:
        command_to_send = 'G'  # Green obstacle is dominant — take green avoidance action
    elif red_critical_area > 0 and red_critical_area == green_critical_area:
        # In the unlikely case of a tie, give priority to red
        command_to_send = 'R'

    # 4. Send command via serial port
    if ser and ser.is_open:
        try:
            # Encode and transmit the decision command over UART
            ser.write(command_to_send.encode('utf-8') + b'\n')
        except serial.SerialException as e:
            # Print error message if transmission fails
            print(f"Error writing to serial port: {e}")
            
    # 5. Display the image 
    cv2.putText(frame, f"Comando: {command_to_send}", (10, 30), cv2.FONT_HERSHEY_SIMPLEX, 1, (255, 255, 255), 2, cv2.LINE_AA)
    

# --- FINAL CLEANUP ---
print("Ending program...")
picam2.stop()
if ser and ser.is_open:
    ser.close()
    print("Serial port closed.")
